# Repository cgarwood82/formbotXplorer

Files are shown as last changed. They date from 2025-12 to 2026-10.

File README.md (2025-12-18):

# Overview
This repo serves as a landing place for files that aren't in the main update manager
for the xplorer. Some of these files may be from the image, some may be from custom
configs that I later generate, but they aren't part of the update process.

This repository is also my primary backup for the printer's Klipper configuration.
All synced configuration files now live under the top-level `config/` directory.

## Repo Structure

### config/
Top-level Klipper configuration and related service configs for the printer. Key items:

- `printer.cfg`: The main entrypoint that `include`s the rest of the stack.
- `variables.cfg`: Runtime/state variables written by Klipper/macros.
- `KlipperScreen.conf`: UI configuration for KlipperScreen.
- `mainsail.cfg`: UI configuration for Mainsail.
- `moonraker.conf`: Moonraker service configuration.
- `crowsnest.conf`: Camera/stream configuration used by crowsnest.
- `timelapse.cfg`: Timelapse add-on configuration.

Subdirectories inside `config/`:

- `0_Xplorer/` — Base, vendor/default profiles
  - `01_Default_CFG/`: Xplorer-provided defaults: basic settings, macros, shell commands,
    and Xplorer variables. Files here should generally not be edited directly.
  - `README.md`: Notes about the default stack.

- `01__User_Custom__CFG/` — User overrides and add-ons
  - Place your custom configuration here (e.g. `overrides.cfg`, toolhead/chamber/LED configs).
  - These files are intended to override or extend the defaults under `0_Xplorer/`.

- `02__Boards_Serials/` — Board serial mappings
  - Per-board serial number config files (e.g. `Mainboard_serial.cfg`, `Tool0_serial.cfg`, etc.).
  - Keeps hardware identifiers separate from functional config.

- `03_Resonance_Measurements/` — Input shaper/resonance data
  - Stored plots and artifacts from resonance measurements for reference/tuning.

- `Macros/` — User macros grouped by purpose (bed leveling, probing, LED state, motion tests,
  print control, etc.). These are included by the main stack via `printer.cfg` or defaults.

### scripts/
wip

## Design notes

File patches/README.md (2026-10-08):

# Local patches to third-party code on the printer

These run on the printer as uncommitted changes in other projects' checkouts.
An update through Moonraker either refuses (the repo shows as dirty) or wipes
them, so re-apply after updating: stash, fast-forward, pop, or `git apply`
the file here.

| Patch | Applies in | Base | Fixes |
|---|---|---|---|
| `afc-AFC_extruder-move_extruder-guards.patch` | `~/AFC-Klipper-Add-On` | DEV 8ba0f7b | Klipper crashes (`stepcompress`, `syncemitter`) when AFC borrows an extruder stepper that is active or synced to another extruder |
| `afc-AFC_led-guard-transmit-error.patch` | `~/AFC-Klipper-Add-On` | DEV 8ba0f7b | Klipper hangs after any MCU shutdown: an AFC LED update's send error escaped the reactor |
| `nevermore-port-release-and-ready-timer.patch` | `~/nevermore-controller` | 6c627d9 | `failed to connect - timed out` on restart (serial port never closed; restarts from an error state never disconnected), and a startup crash on `Unknown heater 'heater_bed'` with Klipper v0.13.0-786 |

None of these are upstream yet. AFC on Klipper v0.13.0-741 or newer needs
AFC from DEV 8ba0f7b or later regardless (the `absolute_extrude` rename).

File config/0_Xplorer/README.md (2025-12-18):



This repository is directly integrated with the Update Manager in the Mainsail interface for the Xplorer 3D printer. 
It serves as the central source for keeping your machine up to date with the latest configurations and resources.

Included in this Repository:
✅ Klipper Configs
All printer configuration files are maintained and regularly updated here.

🛠 Formbot MODs
Official Custom modifications and tweaks made by Formbot.

🧩 STEP Files
3D models for printed parts are included for maintenance or customization.

🧾 Manual
The latest version of the printer manual is available for quick reference.

🧵 Slicer Profiles
Preconfigured slicer profiles to ensure reliable print quality.

Everything in this repository can be accessed directly from the Mainsail interface, allowing users to stay synchronized with project updates without needing to manually manage files.

## 🚫 License and Usage Notice



The design files and associated data in this repository are provided **strictly for personal and non-commercial use** under the terms of the  
**[Creative Commons Attribution-NonCommercial 4.0 International (CC BY-NC 4.0)](https://creativecommons.org/licenses/by-nc/4.0/)** license.

> **⚠️ Commercial use is *not permitted* without prior written consent from Dr. Dan Andrei Marinescu and Jinhua Xinke 3D Technology Co., Ltd. (Formbot)**  
> [formbot3d.com](https://formbot3d.com) · [vivedino.com](https://vivedino.com)  
> This includes (but is not limited to) reproduction, distribution, or integration into commercial products or services.

Unauthorized commercial exploitation may result in legal action.

---

### ☕ Like this project?

You can support Dan – every coffee helps keep the printers running smoothly! 😊



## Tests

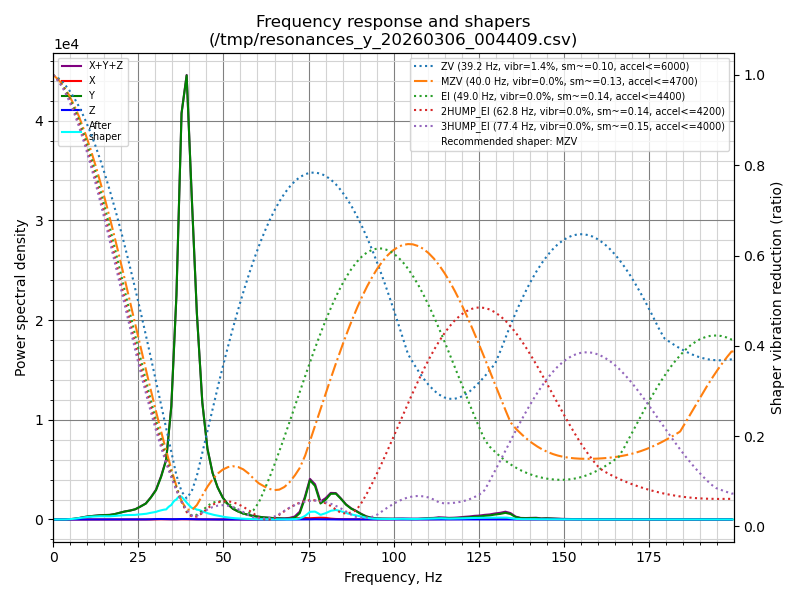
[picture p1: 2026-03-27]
config/03_Resonance_Measurements/shaper_calibrate_y_t2_0046_06032026.png

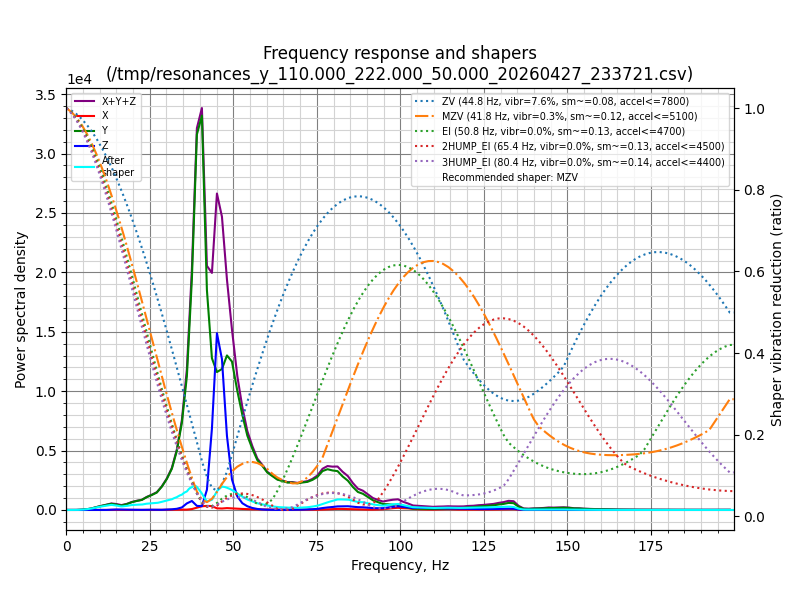
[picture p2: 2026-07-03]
config/03_Resonance_Measurements/shaper_calibrate_y_mccpt1_2339_27042026.png

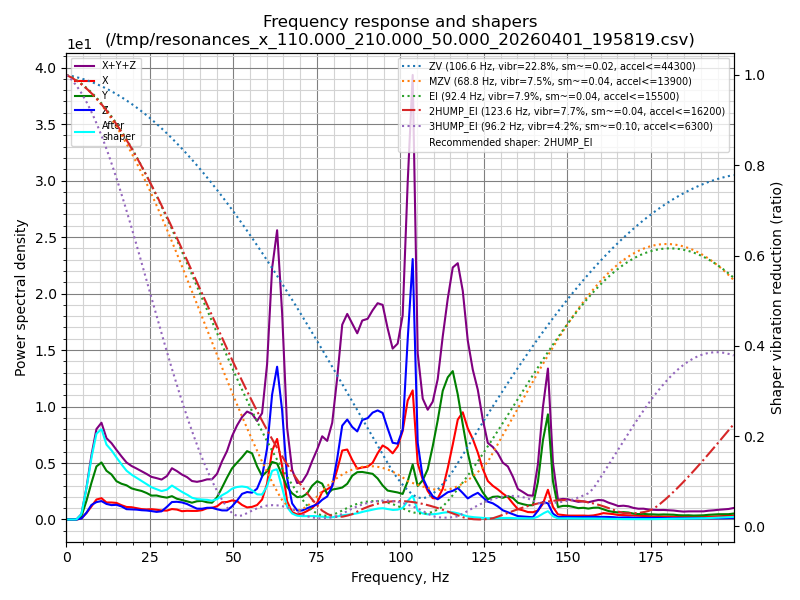
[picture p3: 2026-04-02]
config/03_Resonance_Measurements/shaper_calibrate_x_idexmr_2000_01042026.png

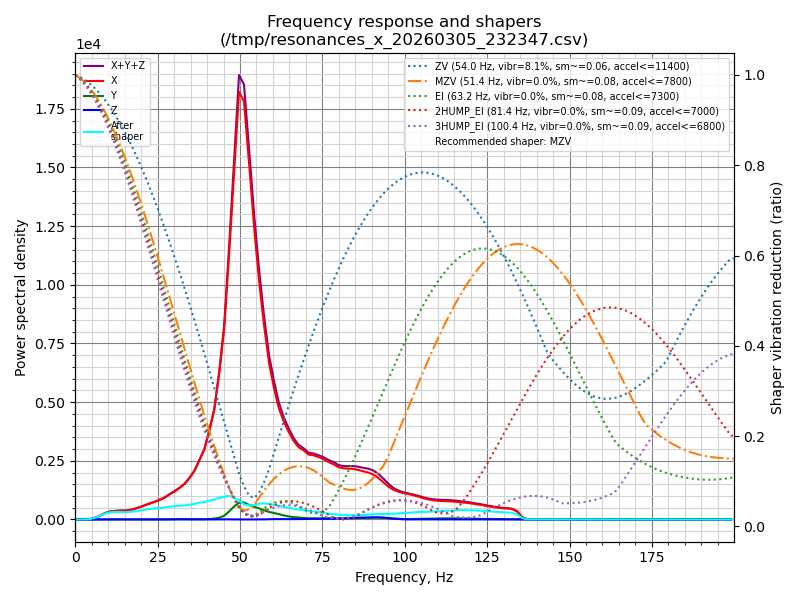
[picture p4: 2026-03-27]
config/03_Resonance_Measurements/shaper_calibrate_x_t3_2326_05032026.png

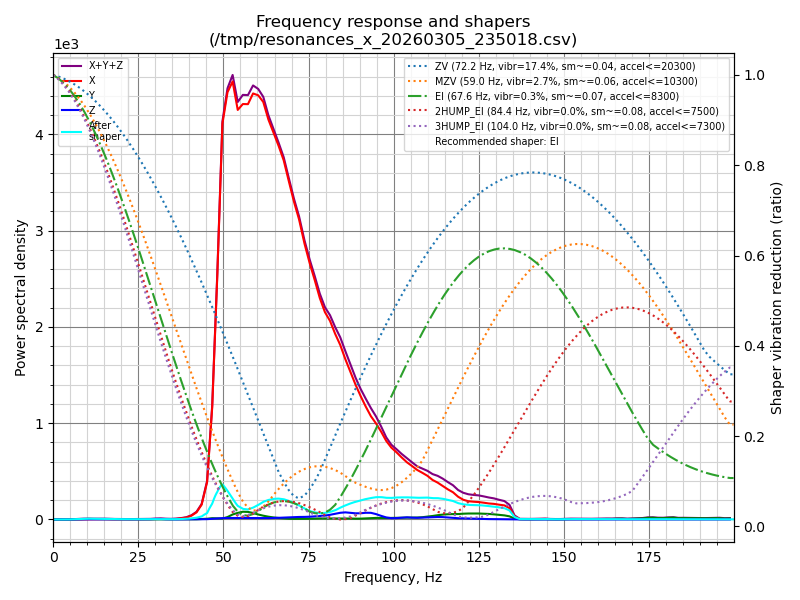
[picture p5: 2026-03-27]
config/03_Resonance_Measurements/shaper_calibrate_x_t2_2352_05032026.png

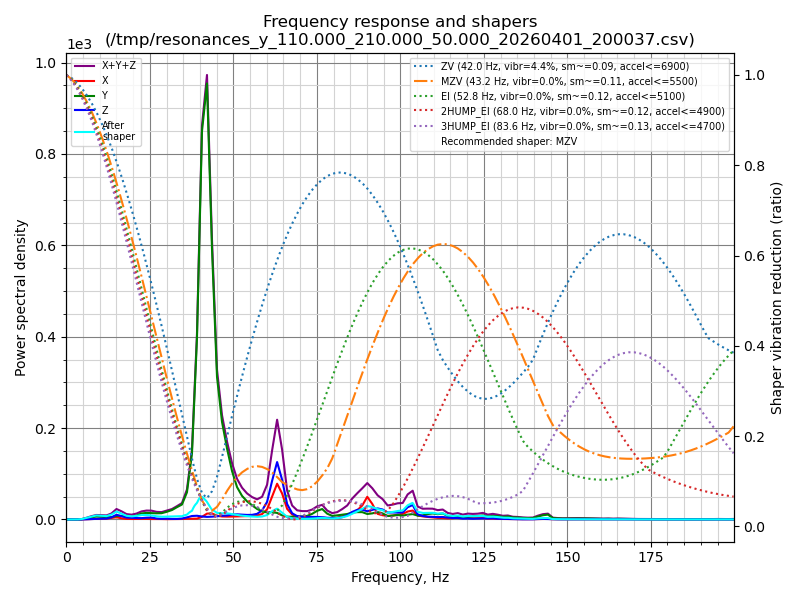
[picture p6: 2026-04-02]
config/03_Resonance_Measurements/shaper_calibrate_y_idexmr_2002_01042026.png

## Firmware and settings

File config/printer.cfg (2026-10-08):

#################################################################################################################
################################# Variables that can be changed by the user ################################################
#################################################################################################################

######################## Description of the variables from Variables.cfg#########################
#                                                                                               #
# bp_zoff >>> Correction coefficient for Automatic Bed Probe calibration                        #
# tprobe >>> Temp of the Nozzles when probing the sensor                                        #
# mesh_tmp >>> Bed temp for Bed Mesh Leveling                                                   #
# h_brush >>> Z_Height for Nozzle brush                                                         #
# pmode >>> print mode for the nex print. 0-primary, 1-copy, 2-mirror                           #
# pwrendp >>> power supply at end of the print.0-off, 1-on                                      #
# >>> Y-offset T1 / T2 / T3 :                                                                   #
# x1offset                                                                                      #
# x2offset                                                                                      #
# x3offset                                                                                      #
# >>> Y-offset T1 / T2 / T3 :                                                                   #
# y1offset                                                                                      #
# y2offset                                                                                      #
# y3offset                                                                                      #
# >>> Z-offset T1 / T2 / T3 :                                                                   #
# z1offset                                                                                      #
# z2offset                                                                                      #
# z3offset                                                                                      #
#                                                                                               #
# >>> input shaper settings                                                                     #
#shaper_type_***                                                                                #
#shaper_freq_***                                                                                #
#                                                                                               #
#################################################################################################

## --> Default CFGs <--#################################--> NO update with [Update Manager] <-- ##
                                                                                                 #
[include ./02__Boards_Serials/Mainboard_serial.cfg]                                              #
[include ./02__Boards_Serials/Tool0_serial.cfg]                                                  #
[include ./02__Boards_Serials/Tool1_serial.cfg]                                                  #
[include ./02__Boards_Serials/Tool2_serial.cfg]                                                 #
[include ./02__Boards_Serials/Tool3_serial.cfg]                                                 #
#[include ./02__Boards_Serials/Hexa_serial.cfg]                                                   #
[include ./02__Boards_Serials/Carto_serial.cfg]                                                   #
[include mainsail.cfg]                                                                           #
[include timelapse.cfg]                                                                          #
#[include moonraker_obico_macros.cfg]                                                            #
                                                                                                 #
##################################################################################################

## --> Formbot CFGs <--#################################--> UPDATED with [Update Manager] ! <-- ##
                                                                                                 #
[include ./0_Xplorer/01_Default_CFG/hack_IQEX.cfg]                                             #
                                                                                                 #
##################################################################################################

##################################################################################################

#### --> User custom CFGs <--################       ############### --> Added  by the user <-- ###
                                                                                                  #
[include ./01__User_Custom__CFG/carto.cfg]                                                        #
[include ./01__User_Custom__CFG/stepperfan.cfg]                                                   #
[include ./01__User_Custom__CFG/toolheads.cfg]                                                    #
[include ./01__User_Custom__CFG/chamberheater.cfg]                                                #
[include ./01__User_Custom__CFG/overrides.cfg]
[include ./01__User_Custom__CFG/nevermore.cfg]
# hexa disabled: its only job was buffer.cfg's manual feed/retract pins
#[include ./01__User_Custom__CFG/buffer.cfg]
[include ./01__User_Custom__CFG/afc_purge_gate.cfg]
[include ./Macros/*.cfg]                                                                          #
[include AFC/*.cfg]
#[include ./01__User_Custom__CFG/****.cfg]                                                        #
#[include ./01__User_Custom__CFG/****.cfg]                                                        #
#[include ./01__User_Custom__CFG/****.cfg]                                                        #
                                                                                                  #
##################################################################################################

##################################################################################################
# General Stuff 
##################################################################################################

##################################
# Specs Xplorer
##################################

[printer]
max_velocity: 500
max_accel: 6000
max_z_velocity: 40
max_z_accel: 300
minimum_cruise_ratio: 0.5
square_corner_velocity: 5.0
kinematics: generic_cartesian

##################################
#  Xplorer specific modules
##################################

[xplorer]               # imports the py modules for the Xplorer into klippy/extras

[trsync_patch]          # when 'True' it increases TRSYNC_TIMEOUT to 0.050 (Klipper default is 0.025) in order to avoid communication errors between the MCUs and the host.
enabled: True

##################################
# Folder to save variables
##################################

[save_variables]
filename:~/printer_data/config/variables.cfg

##################################
# Force Move
##################################

[force_move]
enable_force_move: True

##################################
# Input Shaper
##################################

[input_shaper]

##################################
# Calibrate endstop phases
##################################

[endstop_phase]

##################################
# Support SDCard looping
##################################

[sdcard_loop]

##################################
# Exclude Objects
##################################

[exclude_object]

##################################
# Enable skew correction
##################################

[skew_correction]

##################################
# Enable arcs support
##################################

[gcode_arcs]
resolution: 0.5

##################################
# idle timeout
##################################

[idle_timeout]
TIMEOUT: 3600 #1 hour

##################################
# Respond
##################################

[respond]
default_type: echo

##################################
# Firmware Retraction
##################################
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

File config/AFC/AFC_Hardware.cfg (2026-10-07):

[force_move]
enable_force_move: True

[AFC_extruder extruder]
debounce_delay: 1
pin_tool_start: !Tool0:PC7
pin_tool_end: !Tool0:PA15
tool_stn: 72                    # See documentation for details on how to calculate this value. https://armoredturtle.xyz/docs/afc-klipper-add-on/toolhead/calculation.html
tool_stn_unload: 100            # See documentation for details on how to calculate this value. https://armoredturtle.xyz/docs/afc-klipper-add-on/toolhead/calculation.html
tool_sensor_after_extruder: 0   # Extra distance to move in mm once pre/post sensors are clear. Useful for when only using post sensor, so this distance can be the amount to move to clear extruder gears
tool_unload_speed: 25           # Unload speed in mm/s when unloading toolhead. Default is 25mm/s.
tool_load_speed: 25             # Load speed in mm/s when loading toolhead. Default is 25mm/s.
deadband: 10                    # deadband range to set
toolchanger_unit: Tools         # This is for AFC once AFC can do changes without using KTC
custom_tool_swap: Tool0         # change for the correct number per extruder
custom_unselect: PARK_EXTRUDER  # Add number for the others

[AFC_extruder extruder1]
# Standalone (non-AFC) toolhead: no purge location exists for it.
# _AFC_POOP_VARS purge_loc_xy is a single point (75, 366.5) inside gantry0's
# park zone; sending a gantry1 tool there trips the 27mm inter-gantry
# safe_distance and aborts the tool load mid-print.
enable_standalone_purge: False
debounce_delay: 1
pin_tool_start: !Tool1:PC7
pin_tool_end: !Tool1:PA15
tool_stn: 72                    # See documentation for details on how to calculate this value. https://armoredturtle.xyz/docs/afc-klipper-add-on/toolhead/calculation.html
tool_stn_unload: 100            # See documentation for details on how to calculate this value. https://armoredturtle.xyz/docs/afc-klipper-add-on/toolhead/calculation.html
tool_sensor_after_extruder: 0   # Extra distance to move in mm once pre/post sensors are clear. Useful for when only using post sensor, so this distance can be the amount to move to clear extruder gears
tool_unload_speed: 25           # Unload speed in mm/s when unloading toolhead. Default is 25mm/s.
tool_load_speed: 25             # Load speed in mm/s when loading toolhead. Default is 25mm/s.
deadband: 10                    # deadband range to set
toolchanger_unit: Tools         # This is for AFC once AFC can do changes without using KTC
custom_tool_swap: Tool1         # change for the correct number per extruder
custom_unselect: PARK_EXTRUDER1 # Add number for the others

[AFC_extruder extruder2]
# Standalone (non-AFC) toolhead: no purge location exists for it.
# _AFC_POOP_VARS purge_loc_xy is a single point (75, 366.5) inside gantry0's
# park zone; sending a gantry1 tool there trips the 27mm inter-gantry
# safe_distance and aborts the tool load mid-print.
enable_standalone_purge: False
debounce_delay: 1
pin_tool_start: !Tool2:PC7
pin_tool_end: !Tool2:PA15
tool_stn: 72                    # See documentation for details on how to calculate this value. https://armoredturtle.xyz/docs/afc-klipper-add-on/toolhead/calculation.html
tool_stn_unload: 100            # See documentation for details on how to calculate this value. https://armoredturtle.xyz/docs/afc-klipper-add-on/toolhead/calculation.html
tool_sensor_after_extruder: 0   # Extra distance to move in mm once pre/post sensors are clear. Useful for when only using post sensor, so this distance can be the amount to move to clear extruder gears
tool_unload_speed: 25           # Unload speed in mm/s when unloading toolhead. Default is 25mm/s.
tool_load_speed: 25             # Load speed in mm/s when loading toolhead. Default is 25mm/s.
deadband: 10                    # deadband range to set
toolchanger_unit: Tools         # This is for AFC once AFC can do changes without using KTC
custom_tool_swap: Tool2         # change for the correct number per extruder
custom_unselect: PARK_EXTRUDER2 # Add number for the others
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

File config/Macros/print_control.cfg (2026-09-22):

[gcode_macro PRINT_START]
description: Centralized start sequence with optional multi-extruder + chamber (IDEX/IQEX aware)
# Usage:
#  PRINT_START BED=60 EXTRUDER=220 [EXTRUDER1=210] [EXTRUDER2=0] [EXTRUDER3=0] [CHAMBER=40]

gcode:
    {% set bed      = params.BED|default(0)|float %}
    {% set chamber  = params.CHAMBER|default(0)|float %}
    {% set t0 = params.EXTRUDER|default(0)|float %}
    {% set t1 = params.EXTRUDER1|default(0)|float %}
    {% set t2 = params.EXTRUDER2|default(0)|float %}
    {% set t3 = params.EXTRUDER3|default(0)|float %}
    {% set t4 = params.EXTRUDER4|default(0)|float %}
    {% set t5 = params.EXTRUDER5|default(0)|float %}
    {% set t6 = params.EXTRUDER6|default(0)|float %}
    {% set tool_temps = [t0,t1,t2,t3,t4,t5,t6] %}
    {% set initial_tool = params.INITIAL_TOOL|default(0)|int %}
    {% set initial_temp = tool_temps[initial_tool] %}
    {% set heater_map = ["extruder","extruder","extruder","extruder","extruder1","extruder2","extruder3"] %}
    {% set initial_heater = heater_map[initial_tool] %}
    {% set e_shared = initial_temp if initial_tool < 4 else 0 %}
    {% set e1 = t4 %}
    {% set e2 = t5 %}
    {% set e3 = t6 %}
    {% set afc_hot = 1 if (t0 > 0 or t1 > 0 or t2 > 0 or t3 > 0) else 0 %}
    # Fallbacks only -- these describe the FIRST LAYER (Orca sends first_layer_print_min/max).
    # The real bounds are derived from the exclude_object polygons further down.
    # The old 449 default predates removing the dead space no gantry could reach; the
    # machine's own axis maximum is the truth, so ask the toolhead instead of hardcoding.
    {% set param_min_y = params.MIN_Y|default(0)|float %}
    {% set param_max_y = params.MAX_Y|default(printer.configfile.settings["carriage gantry0"].position_max)|float %}
    {% set xplorer = printer['gcode_macro _XPLORER_VARIABLES'] %}

    # --- Setup ---
    SET_HEATER_TEMPERATURE HEATER=extruder TARGET=150      # force probe temp to override slicer pre-heat when using ooze prevention
    SET_GCODE_OFFSET Z=0                                   # Reset Z offset
    G28                                                    # Home all axes
    G90                                                    # Absolute positioning

    # -- Step 0: Heat Chamber (optional, non-blocking) ---
    {% if chamber|default(0)|float > 0 %}
        # Get the bed away from the heater blast at the home position
        # If Z isn't homed yet, home it (or at least Z) before moving.
        {% if "z" not in printer.toolhead.homed_axes %}
            G28 Z
        {% endif %}
        G90
        G1 Z100 F3000

        # Set chamber temp WITHOUT waiting
        SET_HEATER_TEMPERATURE HEATER=chamber_heater TARGET={chamber|float}
    {% endif %}


    # --- Step 1: Bed heat (optional) ---
    {% if bed > 0 %}
        SET_DISPLAY_TEXT MSG='Heating Bed: { bed }°C'
        M140 S{bed}
        M190 S{bed}
    {% endif %}

    # --- Step 1b: Bed heat-soak -------------------------------------------
    # The AC bed reaches its setpoint far faster than the plate saturates, so
    # probing straight after M190 measures a bed that is still moving --
    # z-tilt, mesh and touch-home all land on geometry that keeps changing
    # underneath them. Hold at temperature first.
    #
    # Duration: SOAK=<minutes> parameter, else the bed_soak_min saved variable,
    # else 15. Living in variables.cfg (like idexsquish/tprobe) means the
    # default is retunable with SAVE_VARIABLE, no restart and no config edit.
    #
    # Emitted as one-minute dwells with a countdown rather than a single long
    # G4, so the UI shows progress instead of appearing hung. NOTE this does
    # not make the soak abortable -- every dwell is queued when this macro
    # renders, so a cancel still waits for the queue to drain.
    #
    # The nozzle stays at its 150C probe temp: TANGO_TIME runs Brush_Tool0
    # before it probes, so any ooze during the hold is cleaned up anyway.
    # {% set soak_min = (params.SOAK|default(printer.save_variables.variables.bed_soak_min|default(15)))|int %}
    # {% if bed > 0 and soak_min > 0 %}
    #    SET_DISPLAY_TEXT MSG='Bed soak: { soak_min } min at { bed }°C'
    #    # Do not leave the nozzle parked a fraction of a mm over a hot plate
    #    # for a quarter of an hour.
    #    G90
    #    G1 Z100 F3000
    #    {% for i in range(soak_min) %}
    #        SET_DISPLAY_TEXT MSG='Bed soak: { soak_min - i } min left ({ bed }°C)'
    #        G4 P60000
    #    {% endfor %}
    #    SET_DISPLAY_TEXT MSG='Bed soak complete'
    # {% endif %}

    # --- Step 2: Any pre-cal/align routine you use ---
    TANGO_TIME EXTRUDER={afc_hot} EXTRUDER1={e1} EXTRUDER2={e2} EXTRUDER3={e3}

    # Set dynamic park positions now that homing/tilt/brush are done.
    #
    # Park clearance has to cover the TALLEST part of the model, not its first layer.
    # MIN_Y/MAX_Y come from first_layer_print_min/max, so a model that flares outward as
    # it climbs -- organic shapes especially -- reaches past the box this math was given,
    # and the printing gantry taps the parked one. That is not theoretical: a print whose
    # first layer ended at Y=268.5 actually reached Y=294.1, so gantry0 parked 26 mm too
    # far forward and sat 13 mm inside the mechanical clearance.
    #
    # Klipper already knows the true XY footprint. Orca emits EXCLUDE_OBJECT_DEFINE before
    # PRINT_START, so the polygons are registered by the time this runs. Fall back to the
    # passed first-layer params when object labelling is off.
    {% set ys = [] %}
    {% for ob in printer.exclude_object.objects %}
        {% for pt in ob.polygon|default([]) %}{% set _ = ys.append(pt[1]|float) %}{% endfor %}
    {% endfor %}
    {% set min_y = ys|min if ys else param_min_y %}
    {% set max_y = ys|max if ys else param_max_y %}

    # Uses park_safe_dist from variables.cfg — the real mechanical clearance
    # between gantries, independent of printer.cfg safe_distance which may be
    # set lower to allow calibration probe reach.
    {% set safe_dist = printer.save_variables.variables.park_safe_dist|float %}
    # Each gantry has its OWN Y range and they are not the same -- gantry0 cannot come
    # forward past its position_min because gantry1 is in front of it on the shared rail.
    # printer.toolhead.axis_* reports only the ACTIVE carriage, so using it would clamp the
    # parked gantry against the printing gantry's limits. Read each carriage's own config,
    # the same way iqex_excludes.cfg does.
    {% set g1 = printer.configfile.settings["dual_carriage gantry1"] %}
    {% set g0 = printer.configfile.settings["carriage gantry0"] %}
    {% set axis_min_y = g1.position_min|float %}
    {% set axis_max_y = g0.position_max|float %}
    {% set want_min = min_y - safe_dist - 10 %}
    {% set want_max = max_y + safe_dist + 10 %}

    # Clamping to the axis limits is still necessary, but it must not be silent: a clamp
    # means the requested clearance was NOT achieved, which is exactly the state that let a
    # gantry get tapped. Say so loudly rather than parking somewhere known to be unsafe.
    {% if want_max > axis_max_y %}
        { action_respond_info("PRINT_START WARNING: model reaches Y=" ~ max_y|round(2) ~
          ", so gantry0 wants Y=" ~ want_max|round(2) ~ " but the axis maximum is " ~
          axis_max_y|round(2) ~ ". Parking at the limit leaves " ~ (axis_max_y - max_y)|round(2) ~
          "mm of the " ~ safe_dist|round(1) ~ "mm clearance. COLLISION RISK -- move the model forward.") }
    {% endif %}
    # No matching warning for the front side, deliberately. gantry1 parks at park_min and
    # gantry0 does the printing there, but gantry0's own position_min (77.5) is a hard stop
    # it cannot cross -- gantry1 sits in front of it on the shared rail. With gantry1 parked
    # at its -1 limit the separation is a fixed 78.5mm no matter what the model does, so a
    # per-print warning would fire on almost every job and train us to ignore the rear one,
    # which is the side with no hardware stop and the side that actually got tapped.

    {% set park_min = [axis_min_y, want_min] | max %}
    {% set park_max = [axis_max_y, want_max] | min %}
    SET_GCODE_VARIABLE MACRO=_XPLORER_VARIABLES VARIABLE=park_min_y VALUE={park_min}
    SET_GCODE_VARIABLE MACRO=_XPLORER_VARIABLES VARIABLE=park_max_y VALUE={park_max}

    # --- Step 3: Tool preheats without changing active tool ---
    SET_DISPLAY_TEXT MSG='Heating Gantry 0: e0: { e_shared }°C & e1: { e1 }°C'
    {% if e_shared > 0 %} SET_HEATER_TEMPERATURE HEATER=extruder  TARGET={e_shared} {% endif %}
    {% if e1 > 0 %} SET_HEATER_TEMPERATURE HEATER=extruder1 TARGET={e1} {% endif %}
    {% if e_shared > 0 %} TEMPERATURE_WAIT   SENSOR=extruder  MINIMUM={e_shared}   MAXIMUM={e_shared+1} {% endif %}
    {% if e1 > 0 %} TEMPERATURE_WAIT   SENSOR=extruder1 MINIMUM={e1}   MAXIMUM={e1+1} {% endif %}
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

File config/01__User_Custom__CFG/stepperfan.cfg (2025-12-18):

[controller_fan stepper_fan]
pin:PF9
cycle_time: 0.1                  # Cycle time
max_power: 1.0                   # Maximum power
shutdown_speed: 0.0              # Shutdown speed
fan_speed: 1.0                   # Fan speed when heater or stepper driver is active (0.0 to 1.0). Default is 1.0.
idle_timeout: 90                 # Time in seconds to keep the fan running after the stepper driver or heater is no longer active. Default is 30 seconds.
idle_speed: 1.0                  # Fan speed after the stepper driver is no longer active and before idle_timeout is reached (0.0 to 1.0). Default is fan_speed.
stepper: stepper y, stepper y1, stepper y2, stepper y3, stepper x, stepper x1, stepper x2, stepper x3

[temperature_fan mcu_fan]
pin: PF6
control: pid
target_temp: 50
max_power: 1.0
min_temp: 0
max_temp: 85
off_below: 0.2
kick_start_time: 0.5
sensor_type:temperature_host
pid_Kp: 5.0
pid_Ki: 0.20
pid_Kd: 50.0

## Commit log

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2025-11-01 Fix typos in resonance calibration macros and standardize messaging across configuration files.
    [Xp_Macros_2xGantry.cfg, Xp_Macros_IDEX.cfg, Xp_Macros_SINGLE.cfg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]
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2025-11-03 Update configuration to include hack toolhead files for Tool0-Tool3
    Replaces Xplorer toolhead files with hack_t0 to hack_t3 in default configuration.
    [hack_IQEX.cfg]
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2025-11-03 Replace Xplorer SmartSensor files with hack_SmartSensor files and add configurations for Tool2 and Tool3.
    [hack_IQEX.cfg]
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2025-11-03 Replace `Xp_Basic_Settings.cfg` with `hack_Basic_Settings.cfg` in default configuration and add `hack_Basic_Settings.cfg` file with printer specs and module configurations.
    [hack_Basic_Settings.cfg, hack_IQEX.cfg]
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2025-11-05 Revert "Comment out unused `carriage x` and `dual_carriage dc_x` configurations in `hack_X_Axis_IQEX.cfg` to streamline the setup."
    This reverts commit a5c35424ea94ea4f6e0ae519406f05eb4d981b0d.
    [hack_X_Axis_IQEX.cfg]
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2025-11-06 Update Y-axis configuration in `hack_Y_Axis_IQEX.cfg`: swap `endstop_pin` mappings for `carriage y` and `dual_carriage dc_y`.
    [hack_Y_Axis_IQEX.cfg]
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2025-11-08 Refine and improve prime line macros with separate A→B and B→A variants; remove reverse logic for clarity.
    [prime_lines.cfg]
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2025-11-08 Fix bed leveling macro: replace `CARTOGRAPHER_TOUCH` with `CARTOGRAPHER_TOUCH_PROBE` and remove redundant `G28 Z` command.
    [bed_leveling.cfg]
2025-11-08 Update electronics fan configuration: replace `temperature_fan` with `controller_fan` and adjust fan parameters
    [hack_Basic_Settings.cfg]
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2025-11-09 remove unused safe wait position logic and add missing extruder park commands
    [print_control.cfg]
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2025-11-12 Revert "added macros for Z tilt preparation, adjustment, and debugging"
    This reverts commit 8349ed5ad9c29d04aa7b2aa0bdda4d154730aaa2.
    [hack_probe.cfg]
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2025-11-12 revise logic for heating only two nozzles at a time to prevent too much power draw
    [hack_print_control.cfg]
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2025-11-14 Revert "reorder extruder syncs, remove unneeded calls to primary, etc before cooking time"
    This reverts commit 0b0b6bcec9a9148f1ba8556ecbaa8e4eab2c4bd9.
    [hack_Macros_IQEX.cfg]
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2025-11-16 Revert "trying to get OG stuff to work"
    This reverts commit fe16648fdbb2263b4657eaa398fc09c1a4f54979.
    [Xp_Calibrate_offsets_IQEX.cfg]
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2025-11-16 syntax issue from converting to a g1 call from a macro call
    [hack_Calibration_offsets_idex.cfg]
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2025-12-18 Klipper fork (#2)
    * prep printer.cfg for iqex
    * accommodate extruders 2 and 3
    * revise steppers controlling the fan state
    * errant comma removal
    * update z tilt for new mechanics
    * AI comment I missed
    * adding latest changes
    * updated vars
    * changed stepper names to align with upstream
    * removed incorrect stepper reference
    * move toolhood mods to user cfgs
    * migrating configs and macros from update manager repo
    * delete debug macro
    * running config push
    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
    [Hexa_serial.cfg, Mainboard_serial.cfg, SKR_serial.cfg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]
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2026-02-24 Dev (#4)
    * initial buffer config
    * change names of pins
    * change names of macros
    * change names of macros
    * change names of macros
    * change names of macros and pins
    * comment out debounce
    * removing underscores from pins and macros
    * clean up cancel and end macros
    * latest configs
    * remove unused macros and cleanup configs
    * do tool calibration without homing to ensure positional accuracy
    * incorporate auto calibrate into my print start macro only if pmode is primary
    * Tired of waiting on filament temps to stabilize.
    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
    [AFC.cfg, AFC_Hardware.cfg, AFC_Lite.cfg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]
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2026-03-30 add conditional retraction on tool change for physical toolheads
    Adds a _RETRACT_IF_PRINTING helper macro that retracts the outgoing
    tool before carriage park moves, but only during an active or paused
    print and only when the nozzle is hot enough to extrude. This prevents
    stringing during XY carriage travel without affecting cold/manual tool
    switches.
    Retraction amount is driven by tc_retract in variables.cfg (default
    0.8mm) so it can be tuned at runtime via SAVE_VARIABLE without a
    restart. Each Tool0-Tool3 macro calls the helper as its first action,
    after AFC has already performed its z_hop.
    [overrides.cfg, variables.cfg]
2026-03-30 dynamic Y park positions based on print bounding box
    PRINT_START now accepts MIN_Y and MAX_Y from the slicer and computes
    optimal park positions for each gantry, replacing the fixed Y=0/449
    extremes. Gantry0 parks at (MAX_Y - y_off_dg + 10) machine Y instead
    of always going to 449; for a 100x100mm print this saves ~400mm of Y
    travel per tool change. Gantry1 parks at (MIN_Y - 10) instead of
    always going to 0, saving travel when the print is centered on the bed.
    Park positions fall back to safe extremes (0/449) in non-primary
    print modes (copy, mirror) via a pmode == 0 guard in each PARK macro.
    [hack_Macros_IQEX.cfg, my_Xplorer_vars.cfg, print_control.cfg]
2026-03-30 fix _RETRACT_IF_PRINTING using relative extrusion mode
    G1 E-x in absolute extrusion mode (M82, the OrcaSlicer default) moves
    the extruder TO position -x, not BY -x. Mid-print with E at thousands
    of mm this caused a massive retraction that ejected the filament.
    Wrap the move in SAVE/RESTORE_GCODE_STATE and force M83 (relative)
    so the retract is always exactly tc_retract mm regardless of the
    current absolute E position. State is fully restored afterwards.
    [overrides.cfg]
2026-03-31 fix park positions to respect safe_distance between gantrys
    park_min_y and park_max_y were only offsetting 10mm from the print
    bounding box, which is far less than the 70mm safe_distance required
    between gantry0 and gantry1. This caused gantry collisions when the
    active tool printed near the front/back edges of the print area.
    Now reads safe_distance from config and adds it to the margin so
    the parked gantry always stays at least 80mm clear of the print extents.
    [print_control.cfg]
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2026-03-31 fix park_max_y: add y_off_dg instead of subtracting it
    Subtracting y_off_dg was bringing gantry0's park position too far
    forward (315mm), too close to where gantry1 prints at MAX_Y. Adding
    y_off_dg pushes gantry0 back to 430mm, giving sufficient clearance.
    [print_control.cfg]
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2026-04-04 reset dynamic park positions to printer limits on print end/cancel
    END_PRINT and CANCEL_PRINT now reset park_min_y to 0 and park_max_y to
    the printer's actual Y axis maximum so each new print starts from stock
    parking positions before PRINT_START recomputes them from the slicer bbox.
    [print_control.cfg]
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2026-04-04 fix park position calc: use config safe_distance, drop y_off_dg, cap at 392
    Pull safe_dist from [dual_carriage gantry1].safe_distance instead of
    hardcoding. Remove y_off_dg from park_min — gantry1 shares the same
    coordinate space as gantry0 so no offset translation is needed. Cap
    park_max at 392 (actual Y axis maximum) instead of 449.
    [print_control.cfg]
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2026-04-04 improve tools_calibrate logging and fix trigger_to_bottom_z sign
    - Remove basicConfig/os import; use named logger via Klipper's log system
    - Add gcmd.respond_info() output for each probe tap, XY spread, pass
    summaries, and final offsets so values are visible in Mainsail console
    - Fix trigger_to_bottom_z sign: was adding pre-travel to z_offset,
    should subtract (switch fires 0.3mm below true nozzle contact)
    [tools_calibrate.py]
2026-04-04 overhaul tool offset calibration macros
    - Remove y_off_dg from Tool2/Tool3 SET_GCODE_OFFSET; gantries share
    coordinate space so no offset translation needed
    - Remove dead xplorer variable fetch from _save_offsets_t2/t3
    - Add samples_tolerance_retries: 3 to [tools_calibrate]
    - Fix lower_z: 0.3 -> 0.6 and add trigger_to_bottom_z: 0.3 (measured)
    - Remove AUTO_CALIBRATE_probe_offset and _save_offsets_bedprobe;
    redundant with Cartographer handling Z natively
    - Rewrite AUTO_CALIBRATE_tool_offsets: full G28, Z_TILT_ADJUST,
    brush T0, drop to 150 for CARTOGRAPHER_TOUCH_HOME, reheat all tools,
    brush T1/T2/T3, then calibrate; remove duplicate M104 heater commands;
    fix F1000 typo to F9000 on T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
    [Xp_Calibrate_offsets_IQEX.cfg, hack_Macros_IQEX.cfg]
2026-04-04 fix TEMPERATURE_WAIT before CARTOGRAPHER_TOUCH_HOME to use MAXIMUM
    Was using MINIMUM=150 which passes immediately when cooling from 170.
    Need MAXIMUM=150 to actually wait for nozzle to drop below 150.
    [Xp_Calibrate_offsets_IQEX.cfg]
2026-04-04 decouple park safe distance from printer.cfg safe_distance
    Store real mechanical clearance (40mm) in variables.cfg as park_safe_dist
    so print_control.cfg park math is independent of printer.cfg safe_distance,
    which may be tuned lower to allow calibration probe reach.
    [print_control.cfg, variables.cfg]
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2026-04-04 replace SKEW_PROFILE LOAD=SKEW0 with SET_SKEW CLEAR=1 at startup
    SKEW0 is all zeros and never calibrated. Use explicit clear instead
    so startup state is unambiguous and independent of the legacy profile.
    [hack_Macros_IQEX.cfg]
2026-04-04 silence SET_INPUT_SHAPER console output and fix skew in active Tool macros
    Add silence_input_shaper.py Klipper module that wraps SET_INPUT_SHAPER
    to suppress respond_info output, eliminating console spam on toolchange.
    Enable via [silence_input_shaper] in overrides.cfg.
    Also add SKEW_PROFILE LOAD=gantry0/gantry1 to overrides.cfg Tool macros
    (the ones that actually run — hack_Macros_IQEX.cfg Tool macros are
    overridden by these and were getting skew loads that never fired).
    [overrides.cfg]
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2026-04-04 guard SKEW_PROFILE LOAD in Tool macros to printing state only
    Loading gantry skew profiles during manual toolchanges or calibration
    causes 'Move out of range' errors when a carriage is near X=0 at high Y
    (skew correction: 0.0028 * 391 = 1.095mm pushes X negative).
    Only load the per-gantry skew when printing or paused; clear skew
    otherwise. PRINT_START still sets the correct profile for the initial tool.
    [overrides.cfg]
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2026-04-04 fix skew boundary errors by clearing skew at toolchange start
    Root cause: gantry1 skew (+0.0028) left active from Tool2/Tool3
    caused PARK macros to fail when moving to X=0 at Y=391
    (0.0028 * 391 = 1.095mm correction pushed X to -1.095).
    Fix: SET_SKEW CLEAR=1 at the top of every Tool macro before any
    park moves run. Skew is then reloaded at the end only when printing,
    paused, or calibrating. Remove redundant else SET_SKEW CLEAR=1
    branches since the top-of-macro clear handles that case.
    [overrides.cfg]
2026-04-04 simplify skew loading — unconditional now that clear-at-top is the fix
    SET_SKEW CLEAR=1 at toolchange start is the real boundary crash fix.
    Remove print_stats.state guard and _SKEW_STATE flag — skew now loads
    unconditionally at the end of every Tool macro for all contexts.
    [Xp_Calibrate_offsets_IQEX.cfg, overrides.cfg]
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2026-04-28 remove all toolhead-takeover (ttovr) functionality
    Toolhead takeover (the "if T1 runs out of filament, T0 takes over"
    strategy) isn't used. Removing all of it:
    - variables.cfg: drop ttovr, ttover_resume keys
    - printer.cfg: drop ttovr documentation comment
    - print_control.cfg: drop ttovr/ttover_resume SAVE_VARIABLE calls
    in PRINT_START and _COMMON_PRINT_CLEANUP; update cleanup comment
    - hack_Macros_IQEX.cfg:
    - SET_PRINT_MODE: drop the ttovr-incompatibility checks; print
    modes now save unconditionally
    - var_startup: drop ttovr=0 init
    - delete SET_TOOLHEAD_TAKEOVER, QUERY_TOOLHEAD_TAKEOVER macros
    - delete TTOVER0, TTOVER1, TTOVER2, TTOVER3 (4 ~110-line macros
    that handled per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
    [hack_Macros_IQEX.cfg, print_control.cfg, printer.cfg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]
2026-04-28 SET_PRINT_MODE / START_PRINTING_MODE: drop rename_existing dependency
    Klipper was failing with "Existing command 'START_PRINTING_MODE' not
    found in gcode_macro rename" — the rename_existing approach assumes
    the base macros are defined before iqex-modes.cfg loads, but on the
    printer side this isn't reliable.
    Make iqex-modes.cfg the single source of truth instead:
    - Delete START_PRINTING_MODE and SET_PRINT_MODE definitions from
    hack_Macros_IQEX.cfg (~57 lines)
    - Replace the rename_existing wrappers in iqex-modes.cfg with
    self-contained macros that handle all 7 modes (existing 0-4 +
    new 5/6) inline
    No more dependency on the upstream-managed file.
    [hack_Macros_IQEX.cfg, iqex-modes.cfg]
2026-04-28 RESONANCE_CALIBRATION_MULTICOLOR_*: keep inactive tools at their parks
    The previous calibration macros called ACTIVATE_MULTICOLOR_*_MODE01,
    which parks t1/t3 in the IDEX staging area at x_cop_idex (=200).
    That's the correct production behavior but wrong for shaper measurement —
    the moving system in real use has t1/t3 at their actual rest X (=419).
    Same problem on the phase-1 → phase-2 swap: t0/t2 would inactivate
    at the test-end position instead of their rest X (=0).
    Rewrite both calibration macros to:
    1. Park t1/t3 at X=419 and t2 at X=0 via a new _MC_CALIBRATE_PARK_INACTIVES
    helper, then activate t0 at X=0.
    2. Position gantries and set up COPY/MIRROR modes inline (no production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
    [iqex-modes.cfg]
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2026-04-28 _PARK_AND_DISABLE_TOOL: skip Y far-back park in multicolor modes
    In multicolor copy/mirror (pmode 5/6), the inactive carriages stay
    where the kinematics last positioned them. The "fly to gantry Y
    position_max/min" behavior — useful in single-tool / IDEX prints to
    keep the parked carriage out of the print's exclude area — is
    unwanted here because the slicer is already arranging things so the
    inactive zone is never visited.
    Force park_gantry0 / park_gantry1 to False when pmode is in (5,6).
    The X parking (G1 X{params.PARKING_POSITION}) still runs — only the
    Y move is suppressed. Single-tool and existing IDEX/IQEX modes
    keep their current behavior.
    [iqex_excludes.cfg]
2026-04-28 Revert "_PARK_AND_DISABLE_TOOL: skip Y far-back park in multicolor modes"
    This reverts commit 05083d7bbaf2d20a7384d9776ce52a3bd9b5b3d0.
    [iqex_excludes.cfg]
2026-04-28 PARK_extruder*: gate entire body on pmode (skip in multicolor)
    Wrap PARK_extruder, PARK_extruder1, PARK_extruder2, PARK_extruder3
    bodies in {% if pmode not in [5,6] %}. In multicolor copy/mirror
    modes the inactive carriages are managed by the _MC_TOOL* helpers
    (set INACTIVE, freeze in place); the per-tool park dance — Y
    far-back move, gantry switching, X park, shaper swap — would
    break the multicolor COPY/MIRROR state and is unwanted.
    AFC's tool-change firmware calls Tool<n>, which in non-multicolor
    modes calls PARK_extruder<other>, which is what fires the Y move.
    Gating the macro body itself is the cleanest defense: regardless
    of caller, in multicolor mode these macros become no-ops.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
    [hack_Macros_IQEX.cfg]
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2026-04-28 Tool0/Tool1: dispatch on actual gantry1 state, not pmode intent
    SET_PRINT_MODE MODE=MULTICOLOR_COPY01 just records pmode=5 as
    "this is what I want for the next print". The actual mode (carriage
    COPY/MIRROR relationships) doesn't engage until ACTIVATE_MULTICOLOR_*
    _MODE01 runs from START_PRINTING_MODE inside PRINT_START.
    Previously the Tool0/Tool1 dispatcher checked pmode, which meant
    any tool change between SET_PRINT_MODE and START_PRINTING_MODE
    (e.g. AFC's initial-tool load at PRINT_START step 11) would route
    to _MC_TOOL0/_MC_TOOL1 prematurely — setting carriage tracking
    modes before the activation macro has positioned them.
    Switch the dispatcher to check
    printer.dual_carriage.carriages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
    [overrides.cfg]
2026-04-28 ACTIVATE_MULTICOLOR_*_MODE01: stop moving t1/t3 to staging X=200
    Both activation macros were SET_DUAL_CARRIAGE PRIMARY-ing t1 and t3
    to drag them to x_cop_idex (200) before final-mode'ing them INACTIVE.
    That puts those carriages over the bed and severely constrains the
    safe-distance limit on the active pair (e.g. T0's max X drops from
    ~361 to ~140 with t1 sitting at X=200).
    T1 and T3 don't need to be positioned during activation — they go
    INACTIVE in the final mode, and INACTIVE carriages don't influence
    the COPY/MIRROR offset setup. Just leave them where they are
    (typically X=421 from G28's home). Same fix applied to both COPY
    and MIRROR variants since the bug was identical.
    Final state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
    [iqex-modes.cfg]
2026-04-29 multicolor toolchange: skew, parking, fan mirror, COPY X-offset
    Four fixes to the multicolor IQEX runtime macros, all uncovered during
    first end-to-end print:
    - _MC_TOOL0/_MC_TOOL1: clear and restore skew around SET_DUAL_CARRIAGE
    swaps. SET swaps fire toolhead.set_position, which resets last_position
    from the (already-skewed) physical pos; with skew active the next G1
    re-skews that value and drifts X past position_min.
    - _MC_TOOL0/_MC_TOOL1: park the leaving carriage pair (G1 X421 / X0)
    before the SET swaps so the incoming tool isn't blocked by the safe
    -distance window of the parked-in-place leaver. Guarded so an
    idempotent re-call (same phase) doesn't move the active tools of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
    [hack_Macros_IQEX.cfg, iqex-modes.cfg]
2026-04-29 multicolor activation: bake x2offset into initial COPY capture
    Slicer's first T2 (line 141 in the slicer's gcode) is a no-op for AFC —
    the lane is already loaded so AFC doesn't fire custom_tool_swap, and
    _MC_TOOL0 never runs at print start. Result: ACTIVATE_MULTICOLOR_*_MODE01
    was the only place that established the t2 COPY offset, and it captured
    0 instead of the calibrated x2offset.
    This caused gantry1's first 1-2 layers to print without the t2-vs-t0
    mounting compensation; once a real toolchange (T4) fired and the next
    T2 ran _MC_TOOL0, the offset jumped to 1.251mm, looking like a layer
    shift on gantry1 starting at the layer where T2 returned.
    Park t2 at X=x2offset (not 0) before SET t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
    [iqex-modes.cfg]
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2026-05-25 flash_mcus: support per-MCU flash_device override
    The M8P V2.0 mainboard now talks to the Pi over a CH340 USB-UART
    bridge (/dev/ttyUSB0) into the H7's USART1. Klipper still uses that
    path for runtime comms, but `make flash` has to reach the H7's DFU
    device on the board's native USB port -- which lives on a totally
    different USB bus path -- so passing /dev/ttyUSB0 as FLASH_DEVICE made
    dfu-util search the wrong USB path and fail with 'No DFU capable USB
    device available'.
    Add a `# flash_device:` comment hint in the serial cfg that overrides
    FLASH_DEVICE for `make flash` only, leaving runtime serial: untouched.
    Wire it into the parser, dry-run output, and the flash invocation.
    Apply the overr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
    [Mainboard_serial.cfg]
2026-05-25 flash_mcus: skip MCUs already on target firmware version
    Query moonraker for each active MCU's running mcu_version (only when
    printer.state == "ready" to avoid trusting stale cached values), and
    compare to `git describe --tags --always --dirty` in $KLIPPER_DIR.
    If they match, downgrade the plan row to a skip so we don't reflash
    boards that are already up-to-date. Dry-run output now shows
    current_version + target_version for each FLASH row.
    Also:
    - Add MCU_config/AFC_Lite/klipper.config (Isik's Tech AFC-Lite v1.0,
    STM32H723, USB CDC on PA11/PA12, Katapult-chained app at 0x8020000)
    derived from the existing ~/katapult/.config + the M8P V2.0 WANT_*
    feature set.
    - Remove the broken flash_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
    [Mainboard_serial.cfg]
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2026-08-04 config: snapshot before AFC async-load work
    variables.cfg: z1offset 0.02 -> -0.04 (tool 1 Z recalibration)
    AFC.var.unit: lane1 state after ASA runout (load/prep/hub false,
    material and color cleared, density back to default)
    Baseline taken before touching AFC_extruder.py for the async-load
    stepcompress fix, so there is a known-good config to return to.
    [variables.cfg]
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2026-08-05 config: disable toolhead runout detection (enable_tool_runout)
    The tool_start switches chatter on machine motion -- 1699 transitions
    during one print, zero in 60s at idle -- and a spurious toolhead runout
    pauses the print. Pause is the state to avoid here: it clears AFC's
    actively_printing guard, and G28 Y in PAUSE does not clear an X-axis
    COPY mode, so IDEX copy jobs are exposed there.
    Loading is unaffected. AFC registers tool_start_callback directly on the
    pin via buttons.register_buttons(), which never consults
    runout_helper.sensor_enabled -- only the runout/insert half is gated.
    Box Turtle lane runout is a separate flag (enable_hub_runout, still True),
    so lane prep/load and hub detecti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
    [AFC.cfg]
2026-08-10 macros: park DISABLE_Tx in machine coordinates, add recovery macro
    DISABLE_T0 during an IDEX copy print failed with:
    PARK_AND_DISABLE_TOOL: moving to X-1.0
    !! Move out of range: -1.246 87.906 188.470
    PARKING_POSITION and park_y are taken from the machine axis limits
    (position_min/position_max), but G1 is interpreted in the tool-offset-adjusted
    coordinate space. DISABLE_T0 targets carriage t0 position_min -1.0; with T1's
    offset active (x1offset 0.246875) that resolves to -1.246875, which is
    0.246875mm past the hard stop.
    The macro aims at the limit with zero margin, so any non-zero offset in the
    shrinking direction breaks it. It only ever worked because T0 is the datum tool
    and its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
    [iqex_excludes.cfg]
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2026-08-25 Gate AFC purging to toolheads that can reach the purge location
    AFC exposes purging as one global switch (poop: in AFC/AFC.cfg) with no per-
    toolhead control -- AFC.py TOOL_LOAD() calls do_poop_kick_wipe() unconditionally
    on every genuine lane-to-tool load. _AFC_POOP_VARS purge_loc_xy is the single
    point 75, 366.5, which only T0 can reach:
    T0 X -1..342, gantry0 -> reachable
    T1 X 76..422, gantry0 -> X=75 is 1mm outside its travel
    T2 X -1..342, gantry1 -> no purge location exists on gantry1 at all
    T3 X 76..422, gantry1 -> same
    So a tool change into T1/T2/T3 sent the toolhead to a point Klipper rejects
    ("Move out of range: 75.225 366.611 ..."), AFC caught the error, and th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
    [AFC.cfg, AFC_Hardware.cfg, afc_purge_gate.cfg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]
2026-08-25 Address heaters by name in the pause/resume macros
    PAUSE and RESUME drove the toolhead heaters with M104/M109 T<n>. AFC intercepts
    those and resolves T<n> through its lane map, where T0-T3 are all Box_Turtle
    lanes on `extruder`. `M104 T2` therefore targeted head 0, not extruder2, so
    every one of the four calls landed on the same heater and the other three heads
    were never touched at all.
    Use SET_HEATER_TEMPERATURE HEATER=<name> throughout, which bypasses the lane map
    and addresses the physical heater.
    Two related corrections while in here:
    Standby now requires target > 0 as well as temperature > 100. A head that was
    already cooling -- target 0 but still hot -- was being driven back up to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
    [overrides.cfg]
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
